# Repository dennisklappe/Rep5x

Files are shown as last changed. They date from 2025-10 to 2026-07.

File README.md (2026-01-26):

# Rep5x - Open source 5-axis 3D printer





5-axis printing demonstration

*Rep5x enables complex geometries without support structures through 5-axis printing*

## Overview

Rep5x democratises 5-axis 3D printing by creating an **affordable retrofit system** for consumer desktop 3D printers. The system adds two rotational axes (A and B) to standard XYZ printers, enabling:

- **Support-free printing** of complex overhangs
- **Improved surface quality** through optimal layer orientation  
- **Stronger parts** by aligning layer direction with stress patterns
- **Reduced material waste** by eliminating support structures

## Quick start

**For easier navigation, visit [Rep5x.com](https://rep5x.com) for the same guides in a more user-friendly format.**

### 1. Check hardware support
Currently supported printers:
- **Ender 5 Pro** - Working prototype
- **Ender 3 V3 SE** - Working prototype with full documentation

### 2. Get the files
- **3D printed parts**: `build-guide/printer-specific/[your-printer]/3d-printed-parts/`
- **Parts list**: `build-guide/universal-parts/bill-of-materials/bom-shared.md`
- **Assembly guide**: `build-guide/assembly-instructions-universal.md`
- **Firmware**: Use the [Firmware Builder](https://tools.rep5x.com/firmware-builder/) to generate custom firmware for your setup

### 3. Join the community
**Discord**: https://discord.gg/GNdah82VBg for build support and discussions

⭐ **Star this repo** to support open-source 5-axis printing development!

## Hardware support

| Printer model | Status | Documentation |
|---|---|---|
| Ender 5 Pro | ✅ Working prototype | Minimal |
| Ender 3 V3 SE | ✅ Working prototype | Complete |
| Generic | Guidelines only | Complete |

## Features

### Current capabilities
- **Continuous C-axis rotation** (unlimited yaw movement)
- **>90° B-axis tilt** for complex geometries
- **Slip ring integration** prevents cable tangling
- **Modular design** for different printer platforms

## Project structure

```
Rep5x/
├── build-guide/             # Complete build documentation
│   ├── assembly-guide.md    # Step-by-step assembly instructions
│   ├── universal-parts/     # Components shared across all printers
│   │   ├── 3d-printed-parts/ # Universal STL files and CAD assembly
│   │   ├── bill-of-materials/ # Complete shared parts list
│   │   ├── electronics/     # Wiring diagrams and control boards
│   │   └── firmware/        # General firmware installation guide
│   └── printer-specific/    # Printer-specific adaptations
│       ├── ender-5-pro/     # Ender 5 Pro retrofit (working)
│       └── ender-3-v3-se/   # Ender 3 V3 SE retrofit (working)
├── website/                 # Official Rep5x website (rep5x.com)
└── README.md               # This file
```

## Community & contributing

### Get help & share builds
**Discord**: https://discord.gg/GNdah82VBg
- Build support and troubleshooting
- Share your prints and modifications
- Development discussions

### Contributing
- Report issues and bugs
- Share your printer modifications  
- Submit pull requests for improvements
- Help with documentation
- Request support for new printer models

**Code of Conduct**: Be respectful and constructive in all interactions.

## Roadmap

### Phase 1 (completed)
- [x] Ender 5 Pro working prototype
- [x] Ender 3 V3 SE adaptation
- [x] Complete documentation and assembly guide
- [x] Marlin firmware configuration
- [x] Setting up the Discord community
- [x] Community guidelines for new printer adaptations

### Phase 2 (current)
- [ ] Community testing and documentation feedback
- [ ] Support users building their first Rep5x systems
- [ ] Identify and fill documentation gaps
- [ ] Accelerate development through user contributions
- [ ] Additional printer model support based on community demand

### Community-driven development
The project's future depends on community involvement. We're focusing on enabling makers to:
- **Adapt to new printer models** with community support
- **Improve documentation** through collaborative contributions
- **Develop slicing features** as open-source solutions
- **Share builds and modifications** to help others

Join our [Discord](https://discord.gg/GNdah82VBg) to help shape the project's direction and contribute to new printer model support!

## License

This project is licensed under the GPL v3 License - see the LICENSE file for details.

## Acknowledgments

This project builds upon the work of [Janis Andersons](https://purl.utwente.nl/essays/96771) at the University of Twente's research into multi-axis 3D printing systems.

---

**Questions?** Follow the repository or join our [Discord](https://discord.gg/GNdah82VBg) for updates as new documentation and features are added.

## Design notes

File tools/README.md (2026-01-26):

# Rep5x - Tools

Web-based tools for Rep5x 5-axis 3D printing.

**Live tools:** https://tools.rep5x.com/

## Available tools

### [Firmware Builder](https://tools.rep5x.com/firmware-builder/)
Configure and build custom Rep5x Marlin firmware with cloud compilation. No local toolchain required.

### [Printer Control](https://tools.rep5x.com/printer-control/)
Control your printer directly from the browser. Jog all 5 axes, send G-code commands, and monitor position.

### [Printer Setup](https://tools.rep5x.com/printer-setup/)
Calibrate Z height and C/B axis zero positions before kinematic calibration.

### [LC/LB Measure](https://tools.rep5x.com/lc-lb-measure/)
Measure your printer's LC and LB kinematic parameters with step-by-step guidance.

### [Vase Generator](https://tools.rep5x.com/vase-generator/)
Generate sample 5-axis vase mode G-code to test and demonstrate Rep5x capabilities.

### [G-code Viewer](https://tools.rep5x.com/gcode-viewer/)
Visualise and animate 5-axis G-code files with collision detection.

### [Calibrator](https://tools.rep5x.com/calibrator/)
Find error curves for your 5-axis system across all C and B angles.

### [G-code Corrector](https://tools.rep5x.com/gcode-corrector/)
Apply calibration corrections and inverse kinematics to 5-axis G-code files.

## File structure

```
tools/
├── index.html           # Tools landing page
├── README.md
├── shared/              # Shared components
│   ├── styles.css
│   ├── theme.js
│   ├── storage-manager.js
│   ├── printer-interface.js
│   ├── camera-manager.js
│   ├── header.js
│   ├── footer.js
│   ├── inverse-kinematics.js
│   ├── c-axis-optimizer.js
│   ├── calibration-corrector.js
│   ├── calibration-visualizer.js
│   ├── calibration-visualizer-3d.js
│   └── correction-graph-renderer.js
├── firmware-builder/
├── printer-control/
├── printer-setup/
├── lc-lb-measure/
├── vase-generator/
├── gcode-viewer/
├── calibrator/
└── gcode-corrector/
```

## Support

- **Discord**: [Join our community](https://discord.gg/GNdah82VBg)

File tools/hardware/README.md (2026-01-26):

# Rep5x Tools - Hardware

Shared hardware components for Rep5x web tools.

## Available hardware

### [`rep5x-camera/`](rep5x-camera/)

USB camera module for visual calibration and alignment tasks.

**Used by:**
- [LC/LB Measure](../lc-lb-measure/) - Camera-based LC/LB parameter measurement

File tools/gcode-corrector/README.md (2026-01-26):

# Rep5x - G-code corrector

Apply calibration corrections and inverse kinematics to 5-axis G-code files.

**Live tool:** https://tools.rep5x.com/gcode-corrector/

## Features

- **Calibration correction**: Apply error compensation from calibration data to improve print accuracy
- **Inverse kinematics**: Add software IK to convert tool-tip coordinates to machine coordinates
- **Firmware IK support**: Apply calibration corrections to G-code already processed with firmware IK (firmware IK in the working, will update woon)
- **Visual preview**: 3D visualisation showing uncalibrated vs calibrated nozzle paths
- **Demo generation**: Create calibration test files to verify corrections

## Use cases

### 1. Apply calibration to uncalibrated files
For G-code generated without calibration:
1. Load your calibration data (from [calibrator tool](https://tools.rep5x.com/calibrator/))
2. Upload uncalibrated G-code
3. Enable "Apply calibration corrections"
4. Process and download corrected file

### 2. Add software IK to raw files
For G-code with tool-tip coordinates only:
1. Enter your LC and LB parameters
2. Upload G-code file
3. Enable "Apply inverse kinematics"
4. Process and download with IK applied

### 3. Calibrate firmware IK files (hopefully soon firmware IK will be available!)
For G-code already processed with firmware IK:
1. Load your calibration data
2. Upload firmware IK G-code
3. Enable "Apply calibration corrections"
4. The corrector automatically detects firmware IK and applies calibration in the correct mode
5. Download corrected file

## Quick start

1. Go to https://tools.rep5x.com/gcode-corrector/
2. **Load calibration** (optional): Click "Load calibration data" and select your `.json` file from the [calibrator tool](https://tools.rep5x.com/calibrator/)
3. **Upload G-code**: Drag and drop or click to select your G-code file
4. **Configure options**:
   - Check "Apply inverse kinematics" if your file needs IK (enter LC/LB values)
   - Check "Apply calibration corrections" if you loaded calibration data
5. **Process**: Click "Process G-code"
6. **Download**: Click "Download corrected G-code"

## Processing modes

The corrector supports three processing modes:

### Software IK + Calibration
- Input: Tool-tip coordinates (XYZ at various A/B angles)
- Output: Machine coordinates with IK applied, then calibration corrections applied
- Use for: Raw G-code that needs both IK and calibration

### Calibration only (firmware IK mode)
- Input: G-code already processed with firmware IK
- Output: Calibration corrections applied to existing machine coordinates
- Use for: Files from slicers that apply firmware IK

### IK only
- Input: Tool-tip coordinates
- Output: Machine coordinates with IK applied
- Use for: Testing IK without calibration, or when no calibration data available

## Understanding the visualisation

The 3D preview shows nozzle error patterns with two colored spheres:
- **Red sphere/trail**: C sweep errors (C rotating 0-360° at B=0)
- **Orange sphere/trail**: B sweep errors (B tilting -90 to +90° at C=0)

**Mode toggle** (above the visualizer):
- **Uncalibrated**: Shows full error pattern without calibration applied
- **Calibrated**: Shows residual error after calibration corrections are applied

**What good calibration looks like**: In calibrated mode, both spheres should barely move from the white center marker. If the movement looks similar in both modes, your calibration isn't working well.

**Preview controls** (below the visualizer): The sweep mode buttons (Both, C only, B only, Combined) only change what you see in the animation. Downloaded demo G-code always tests both C and B axes.

## Demo G-code generation

Generate test files to verify your calibration on the actual printer:

1. **Load calibration data**
2. **Set centre position**: Enter XYZ coordinates where the nozzle should stay fixed
3. **Generate**: Click "Uncalibrated" or "Calibrated" to download demo G-code

**What the demo does**: The printer performs a combined A+B sweep (A rotates 360° while B oscillates sinusoidally), testing both axes simultaneously. The nozzle tip should remain at the specified centre position throughout the entire movement.

**Expected results**:
- **Uncalibrated demo**: Nozzle will drift away from centre, showing your printer's error pattern
- **Calibrated demo**: Nozzle should stay at centre (if calibration is working correctly)

Use these demos to:
- Verify calibration accuracy visually on the printer
- Test before applying corrections to real prints
- Compare uncalibrated vs calibrated performance side-by-side

## File structure

```
gcode-corrector/
├── index.html              # Main application
├── README.md               # This file
└── js/
    ├── app.js              # Application controller
    ├── gcode-processor.js  # G-code parsing and correction engine
    └── calibration-corrector.js  # (in /shared) Calibration data handler
```

## G-code header detection

The corrector automatically detects Rep5x G-code headers to determine:
- Whether IK is already applied (software or firmware)
- LC and LB parameters used
- Whether calibration corrections are present
- Which tool generated the file

This helps prevent double-applying corrections.

## Tips

- Always test corrected G-code with demo files first
- Keep your original uncalibrated files as backups
- Recalibrate periodically as your printer's mechanical state changes
- The corrector preserves all comments and metadata from the original file

## Support

- **Discord**: [Join our community](https://discord.gg/GNdah82VBg)

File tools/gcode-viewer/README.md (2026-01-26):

# Rep5x - G-code viewer

Visualise and animate 5-axis G-code files with real-time printhead orientation display.

**Live tool:** https://tools.rep5x.com/gcode-viewer/

## Features

- **5-axis visualisation**: Full support for C-axis (yaw) and B-axis (pitch) movements
- **Inverse kinematics**: Automatically detects and reverses IK corrections to show original path
- **Animation controls**: Play, pause, speed control, and progress scrubbing
- **Collision detection**: Warns when printhead would collide with printed path or bed
- **Interactive 3D view**: Mouse controls for rotating and zooming

## Usage

1. **Load G-code**: Upload a Rep5x G-code file
2. **Review info**: Check file information and IK parameters
3. **Control animation**: Use play/pause and speed slider
4. **Adjust view**: Toggle visibility of path, printhead, and axes

## File structure

```
gcode-viewer/
├── index.html
├── README.md
└── js/
    ├── app.js
    ├── gcode-parser.js
    ├── inverse-kinematics-reverser.js
    ├── animation-engine.js
    ├── collision-detector.js
    ├── scene-objects.js
    ├── camera-controls.js
    ├── ui-controller.js
    ├── file-handler.js
    └── printheads/
        ├── printhead-base.js
        └── ender3-v3-se.js
```

## Support

- **Discord**: [Join our community](https://discord.gg/GNdah82VBg)

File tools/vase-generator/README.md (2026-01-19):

# Rep5x - Vase generator

Generate demonstration G-code files to showcase Rep5x 5-axis printing capabilities with various shapes.

**Live tool:** https://tools.rep5x.com/vase-generator/

## Features

- **Multiple shapes**: Elbow pipe, mushroom
- **Interactive 3D preview**: Real-time visualisation of generated models
- **Configurable parameters**: Diameter, height, layer settings, speeds
- **5-axis toolpaths**: Each shape demonstrates different 5-axis printing techniques
- **Ready-to-print output**: Complete G-code files with inverse kinematics

## Usage

1. **Select shape**: Choose from available shapes in the sidebar
2. **Adjust parameters**: Modify size, layer height, and print speeds
3. **Preview model**: View real-time 3D preview
4. **Generate G-code**: Click generate to create printer-ready G-code
5. **Download file**: Save for printing on your Rep5x printer

## File structure

```
vase-generator/
├── index.html
├── README.md
└── js/
    ├── app.js
    └── shapes/
        ├── elbow-pipe.js
        └── mushroom.js
```

## Support

- **Discord**: [Join our community](https://discord.gg/GNdah82VBg)

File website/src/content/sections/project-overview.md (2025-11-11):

---
title: "Rep5x Project Overview"
description: "An open-source research project developing affordable 5-axis printing retrofits for consumer 3D printers, enabling new printing capabilities through community collaboration."
badge: "Project Features"

list_columns:
  - title: "5-Axis Motion Control <br> Implementation"
    images:
      - "/images/rw2-print-head-cad.webp"
    description: "Adding yaw and pitch rotation to standard 3D printers lets you print complex shapes without support material, reducing reliance on support structures."
    list:
      - icon: "lucide:rotate-3d"
        title: "Coordinated Multi-Axis Movement"
        description: "Continuous yaw rotation and >90° pitch tilt allow parts to be printed from optimal angles."
      - icon: "lucide:minimize"
        title: "Support Structure Reduction"
        description: "Strategic part orientation can eliminate support material for many complex geometries."

  - title: "Open-Source Retrofit System Design"
    images:
      - "/images/blog/github-repo-screenshot.webp"
    description: "Complete documentation and modular design allow adaptation to different printer models, with community contributions driving development forward."
    list_check:
      - "CAD files and build documentation available on GitHub"
      - "Marlin firmware modifications for 5-axis control"
      - "Currently tested on Ender 5 Pro platform"
      - "Community-driven adaptation to additional printer models"
    button:
      enable: true
      label: "View Project"
      link: "https://github.com/dennisklappe/rep5x"
---

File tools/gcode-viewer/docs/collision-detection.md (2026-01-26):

# Collision detection

This document explains how the collision detection system works in the G-code viewer.

## Overview

```mermaid
flowchart TD
    A[User enables collision detection] --> B[Get printhead parameters]
    B --> C[Loop through all G-code commands]
    C --> D{Command has movement?}
    D -->|No| C
    D -->|Yes| E[Update position]
    E --> F{Path > 20 points AND\n> 10 steps since last collision?}
    F -->|No| G{Has extrusion?}
    F -->|Yes| H[Check collisions]
    H --> J{Collision detected?}
    J -->|Yes| K[Record collision point]
    J -->|No| G
    K --> G
    G -->|Yes| I[Add point to printed path]
    G -->|No| C
    I --> C
    C -->|Done| L[Display collision markers]
```

### Why these checks?

- **Path > 20 points**: Skip collision checks at the start when there's barely anything printed yet
- **> 10 steps since last collision**: Avoid recording hundreds of collision points in the same area
- **Has extrusion**: Only extruded material is added to the path (you can't collide with air)
- **All moves are checked**: Both travel moves (G0) and print moves (G1) check for collisions with the printed path

## Collision check process

For each position, the system checks if any part of the printhead collides with the build plate or previously printed path.

```mermaid
flowchart TD
    subgraph Input
        A[Current position X, Y, Z, A, B]
        B[Printed path points]
        C[Printhead geometry]
    end

    A --> D[Build rotation matrix from C and B angles]

    D --> E{Check build plate collisions}
    E --> F[Heatblock corners]
    E --> G[Nozzle bottom edge]
    E --> H[Cable outer end]

    F --> I{Any point Y < 0?}
    G --> I
    H --> I

    I -->|Yes| J[Return: Collision!]
    I -->|No| K{Check path collisions}

    K --> L[For each path point]
    L --> M[Transform to local printhead space]
    M --> N{Inside nozzle cylinder?}
    M --> O{Inside heatblock box?}
    M --> P{Inside cable cylinder?}

    N -->|Yes| J
    O -->|Yes| J
    P -->|Yes| J

    N -->|No| O
    O -->|No| P
    P -->|No| Q{More path points?}
    Q -->|Yes| L
    Q -->|No| R[Return: No collision]
```

## Printhead geometry

The printhead is defined in local space with the nozzle tip at the origin.

```mermaid
flowchart LR
    subgraph Printhead components
        A[Nozzle cylinder]
        B[Heatblock box]
        C[Cable cylinder]
    end

    subgraph Nozzle
        A1[radius: 4.5mm]
        A2[bottom: 2mm]
        A3[top: 8mm]
    end

    subgraph Heatblock
        B1[halfSize: 12 x 10 x 12mm]
        B2[center: 2, 18, 0mm]
    end

    subgraph Cable
        C1[radius: 3mm]
        C2[center: -15, 18, 0mm]
        C3[halfLength: 5mm]
    end

    A --> A1
    A --> A2
    A --> A3
    B --> B1
    B --> B2
    C --> C1
    C --> C2
    C --> C3
```

## Coordinate transformation

The collision detection uses matrix transformations to check collisions efficiently.

```mermaid
flowchart TD
    subgraph "Build plate collision"
        A1[Local printhead point] --> B1[Apply rotation matrix]
        B1 --> C1[Add nozzle tip position]
        C1 --> D1{World Y < 0?}
        D1 -->|Yes| E1[Collision with bed]
    end

    subgraph "Path collision"
        A2[World path point] --> B2[Subtract nozzle tip position]
        B2 --> C2[Apply inverse rotation matrix]
        C2 --> D2[Local space point]
        D2 --> E2{Inside component bounds?}
        E2 -->|Yes| F2[Collision with path]
    end
```

## Component collision checks

### Nozzle cylinder
```
distance_from_axis = sqrt(x² + z²)
collision = distance_from_axis < radius AND y > bottom AND y < top
```

### Heatblock box
```
relative = point - center
collision = |rel.x| < halfSize.x AND |rel.y| < halfSize.y AND |rel.z| < halfSize.z
```

### Cable cylinder (horizontal along X)
```
relative = point - center
distance_from_axis = sqrt(rel.y² + rel.z²)
collision = distance_from_axis < radius AND |rel.x| < halfLength
```

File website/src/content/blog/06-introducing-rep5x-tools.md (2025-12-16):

---
title: 'Introducing Rep5x Tools'
description: 'Browser-based tools to help you set up, calibrate, and control your Rep5x 5-axis printer.'
date: 2025-12-15
image: '/images/blog/tools-overview.webp'
categories: ['tools', 'software']
author:
  name: 'Dennis Klappe'
  designation: 'Masters Student'
  avatar: '/images/team/dennis-klappe.webp'
featured: true
---

**Rep5x Tools** is a collection of browser-based tools to help you set up, calibrate, and use your 5-axis printer. No installation needed, just open your browser and connect to your printer.

<div class="rounded" style="overflow: hidden;">
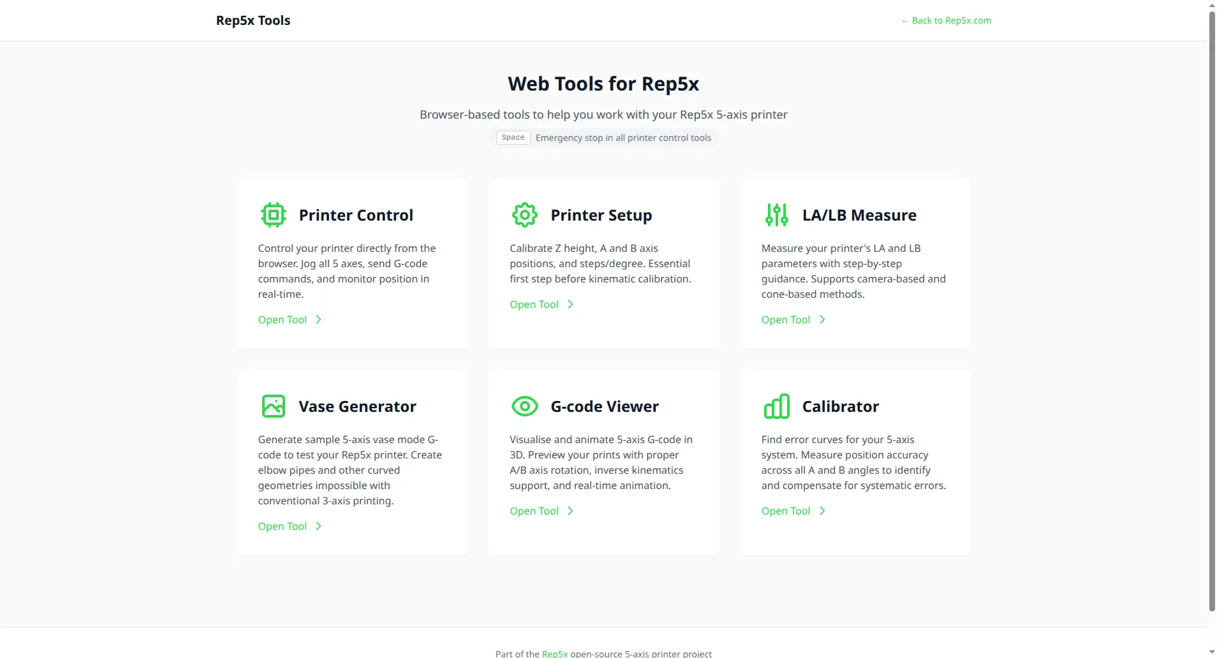
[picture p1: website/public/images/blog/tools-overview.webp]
Rep5x Tools overview

</div>

## Available tools

### Printer Control

Control your printer directly from the browser. Jog all 5 axes, send G-code commands, and monitor position in real-time. Press Space for emergency stop.

<div class="rounded" style="overflow: hidden;">
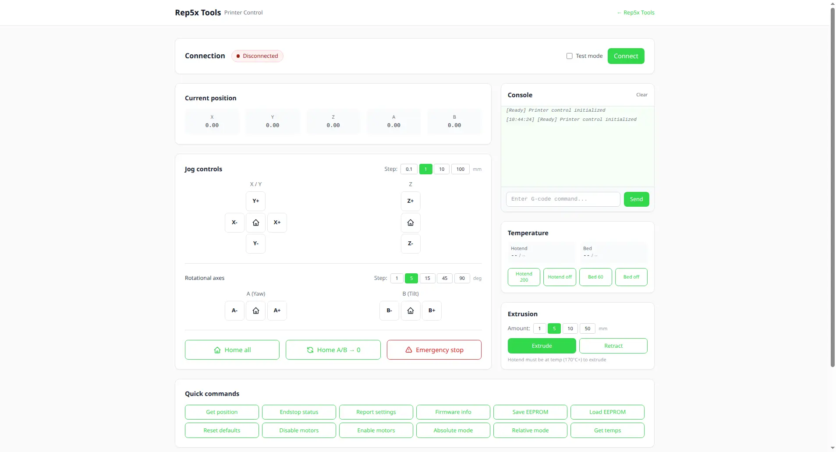
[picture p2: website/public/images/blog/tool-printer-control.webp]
Printer Control tool

</div>

### Printer Setup

Calibrate Z height, A and B axis positions, and steps/degree. This is the essential first step before kinematic calibration.

<div class="rounded" style="overflow: hidden;">
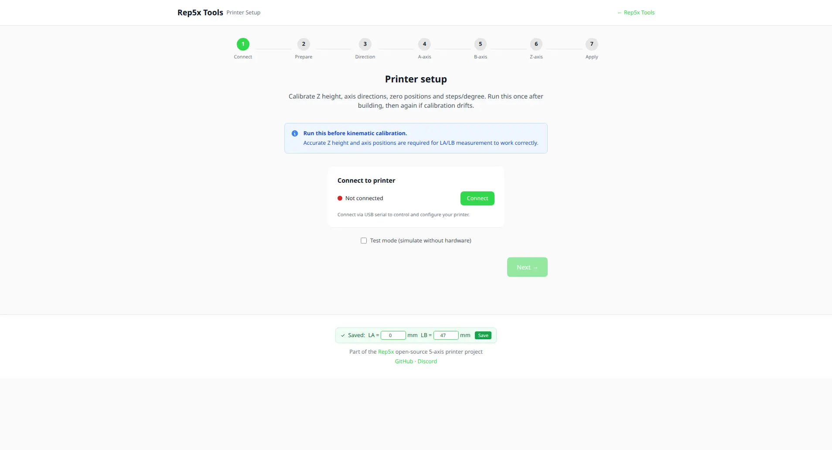
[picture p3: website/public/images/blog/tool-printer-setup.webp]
Printer Setup tool

</div>

### LA/LB Measure

Measure your printer's LA and LB kinematic parameters with step-by-step guidance. Supports both camera-based and cone-based measurement methods.

<div class="rounded" style="overflow: hidden;">
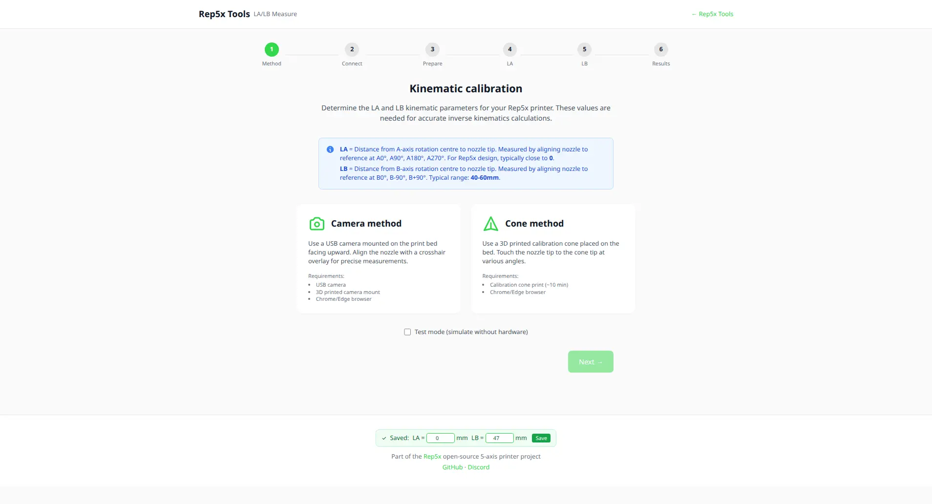
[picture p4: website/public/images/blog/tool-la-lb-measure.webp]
LA/LB Measure tool

</div>

### Vase Generator

Generate sample 5-axis vase mode G-code to test your printer. Create elbow pipes, mushroom vases, and other curved geometries that are impossible with conventional 3-axis printing.

<div class="rounded" style="overflow: hidden;">
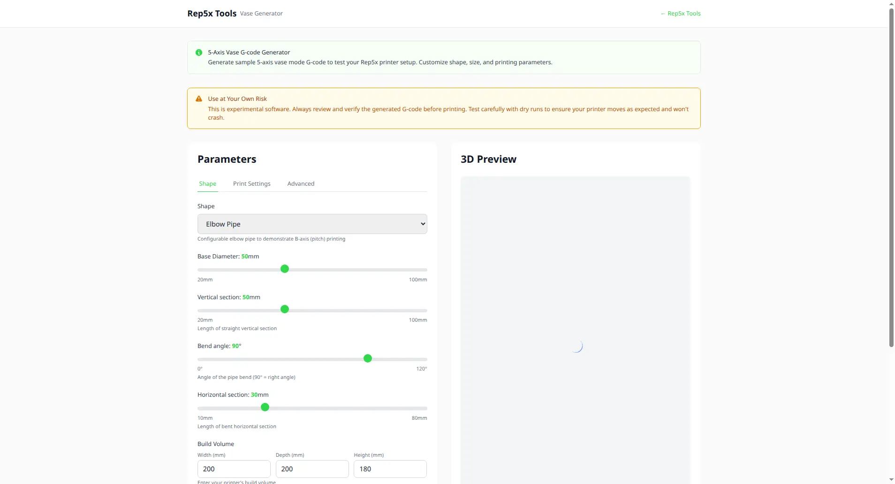
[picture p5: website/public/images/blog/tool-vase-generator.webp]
Vase Generator tool

</div>

### G-code Viewer

Visualise and animate 5-axis G-code in 3D. Preview your prints with proper A/B axis rotation, inverse kinematics support, collision detection, and real-time animation.

<div class="rounded" style="overflow: hidden;">
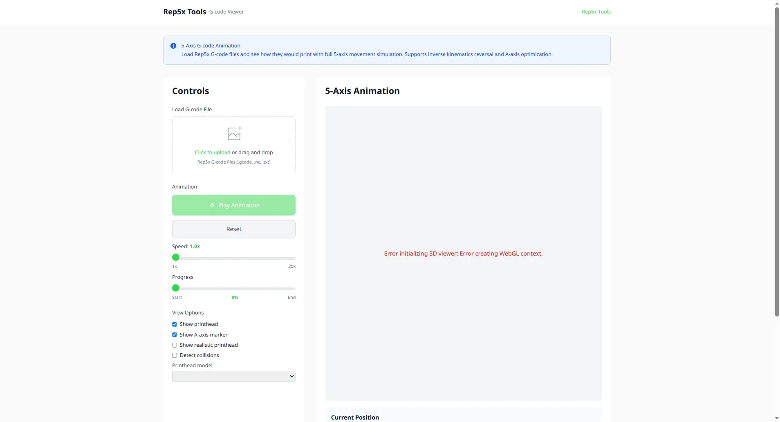
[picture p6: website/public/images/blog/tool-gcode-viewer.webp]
G-code Viewer tool

</div>

## Hardware: Rep5x Camera

Some tools work even better with the optional **Rep5x Camera** module, a simple USB camera with built-in LED lighting that mounts to your printer's bed.

<div class="rounded" style="overflow: hidden;">
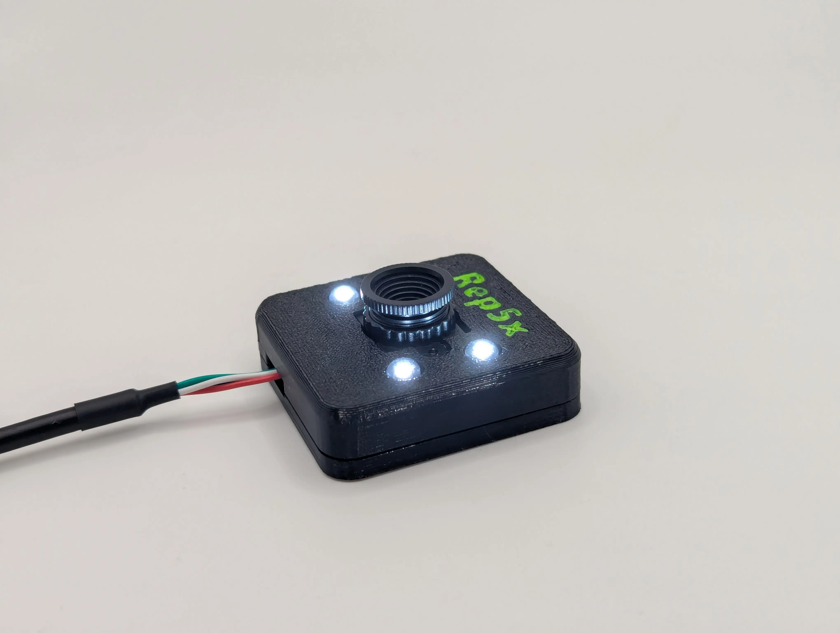
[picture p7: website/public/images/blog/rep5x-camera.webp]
Rep5x Camera module

</div>

The camera enables precise measurements by providing a close-up view of the nozzle. In the LA/LB Measure tool, you align the nozzle tip to a crosshair on screen and confirm the position. Much easier than eyeballing it from the side of your printer.

The upcoming Calibrator tool will also use this camera for automated error mapping across all A and B angles. If you don't want to build the camera module, no problem. **All tools have alternative methods** that work without additional hardware, like the cone-based measurement method already available in LA/LB Measure.

## Coming soon: Calibrator

The **Calibrator** tool is currently in development. It works like bed leveling mesh but for your rotational axes. Measure position errors across different A and B angles to generate error curves, then run your G-code through the tool to apply compensation.

## Try it out

All tools are available at [tools.rep5x.com](https://tools.rep5x.com). Connect to your printer via USB and you're good to go.

Questions or feedback? **[Join our Discord](https://discord.gg/GNdah82VBg)**!

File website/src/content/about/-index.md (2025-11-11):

---
title: "About Rep5x"
meta_title: "About Rep5x"
description: "Open-source 5-axis 3D printing retrofit system developed at University of Twente"
image: "/images/about/ender-5-pro-rw2-printing.webp"

hero:
  title: "Democratising 5-Axis 3D Printing Technology"
  description: "Rep5x is an open-source research project developing affordable retrofit systems that transform consumer 3D printers into 5-axis manufacturing platforms"
  image: "/images/about/ender-5-pro-rw2-printing.webp"

card:
  title: "Research-driven innovation"
  subtitle: "Academic Excellence"
  description: "Rep5x originated from academic research at the University of Twente, building on previous work in multi-axis 3D printing. Our goal is to make advanced manufacturing capabilities accessible to makers, educators, and small businesses through open-source design and comprehensive documentation. The project emphasises community collaboration and knowledge sharing to advance the field of additive manufacturing."
  icon: "lucide:map-pin"

accomplishments:
  enable: true
  list:
    - number: "6"
      prefix: ""
      subtitle: "Total axes (X, Y, Z, E + yaw & pitch)"
    - number: "360"
      prefix: "°"
      subtitle: "Continuous yaw rotation"
    - number: "100"
      prefix: "%"
      subtitle: "Open-source design"
---

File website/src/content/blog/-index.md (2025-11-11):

---
title: "Blog Posts"
meta_title: ""
description: "Rep5x project updates and 5-axis printing insights"
image: "/images/blog/ender-5-pro-rw2-retrofit.webp"

hero:
  title: "Rep5x Development Blog"
  description: "Follow the development journey of open-source 5-axis printing technology, research insights, and community updates"
---

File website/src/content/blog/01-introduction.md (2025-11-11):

---
title: 'The journey begins'
description: 'Introduction to the Rep5x 5-axis printing project and thesis journey at University of Twente'
date: 2025-09-01
image: '/images/blog/ender-5-pro-rw2-retrofit.webp'
categories: ['project', 'introduction']
author:
  name: 'Dennis Klappe'
  designation: 'Masters Student'
  avatar: '/images/team/dennis-klappe.webp'
featured: true
---

Welcome to my thesis blog! I'm Dennis Klappe, a Master's student in Industrial Design Engineering at the University of Twente. I'm not the kind of person who uses social media much or enjoys blogging, but I believe documenting the process well is key to creating a good open-source project. So bear with me as I share this journey over the next nine months, working on making 5-axis FDM 3D printing more accessible.

## The challenge

Most traditional FDM 3D printers work in three axes (X, Y, and Z). Adding two rotational axes enables printing complex geometries without supports, better surface quality, and less waste. But current 5-axis printers are expensive and complex.

My goal: develop an affordable, open-source 5-axis system that works with common desktop 3D printers.

## Building on previous work

This project builds on my supervisor Janis Andersons's [master's thesis](https://purl.utwente.nl/essays/96771) from 2023. He developed a 5-axis printer using a 2-axis print-head retrofit (adding 2 rotational axes to the standard 3-axis system), proving that multi-axis printing can be accessible. My work continues this development, focusing on refinement and democratisation.

## What's coming

Over the coming months, I'll probably work on:
- Understanding user needs
- Creating build documentation
- Testing real-world performance
- Building a community around the project
- Updating the hardware the adapt to mutliple existing printers

## Get involved

This blog will document the development process, successes, failures, and everything in between. Whether you're a maker, educator, or just curious about 3D printing's future, follow along.

Want to discuss the project or contribute? [Join the Discord](https://discord.gg/75Hy5dMwTJ) to connect with the community.

The best ideas often come from makers and citizen-scientists. Let's democratise 5-axis printing together.

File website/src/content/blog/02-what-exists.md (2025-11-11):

---
title: 'Current state printer'
description: 'Understanding the existing Rep5x hardware and building on previous research achievements'
date: 2025-09-15
image: '/images/blog/cad-model-rw2-print-head.webp'
categories: ['hardware', 'history']
author:
  name: 'Dennis Klappe'
  designation: 'Masters Student'
  avatar: '/images/team/dennis-klappe.webp'
---

In 2023, my supervisor Janis Andersons built the first version of this 5-axis printer for his master's thesis. He took a standard Ender 5 Pro and added a 2-axis print-head retrofit that could tilt and rotate the nozzle.

## What Janis achieved

Janis designed what he called the "robot wrist" (RW2), a print-head that adds two rotational axes to a standard printer. The A-axis rotates around the vertical Z-axis (like turning your head left and right), while the B-axis tilts the nozzle forward and back.

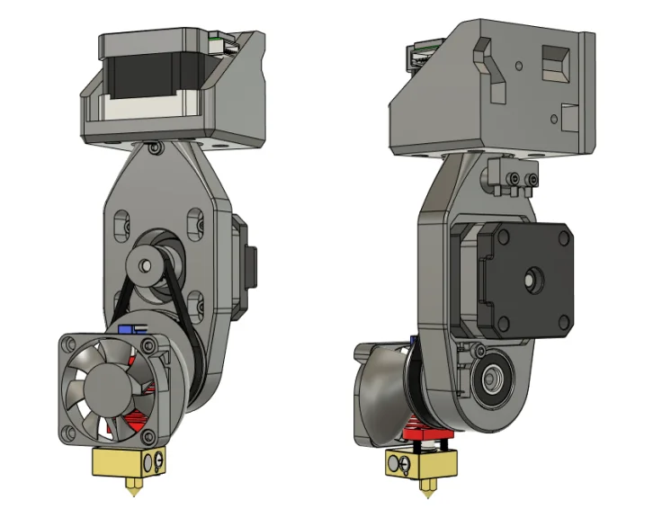
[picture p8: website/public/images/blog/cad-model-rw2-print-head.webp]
CAD model of RW2 print-head

*CAD model of RW2 print-head (Andersons, 2023)*

He kept it simple. The design uses standard NEMA17 stepper motors with 3 to 1 belt reduction for both axes. Everything can be 3D printed except for some bearings, belts, and electronics. The whole retrofit costs under €150.

His test prints proved the concept. He printed tubes with 90-degree overhangs without any supports. Surface quality on angled surfaces improved compared to standard printing. The dimensional accuracy stayed within 0.6mm, which is decent for a first prototype.

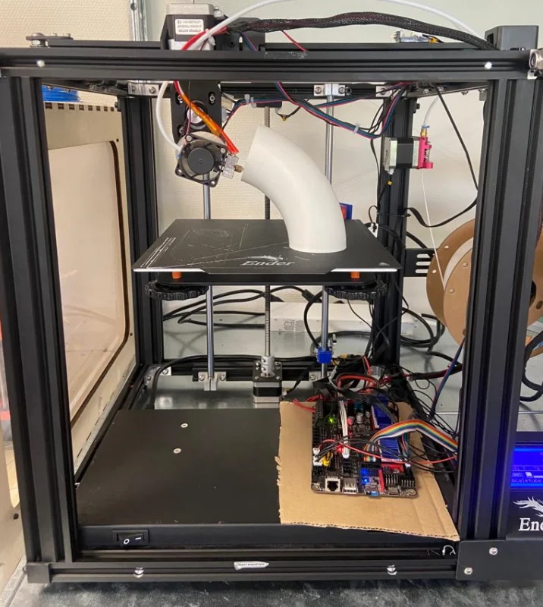
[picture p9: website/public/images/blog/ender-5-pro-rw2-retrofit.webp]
Ender 5 Pro with retrofit RW2 print-head, executing a large print

*Ender 5 Pro with retrofit RW2 print-head, executing a large print (Andersons, 2023)*

## Hardware details

Why did Janis choose specific components? Most 3D printer boards support 5 stepper motors (X, Y, Z1, Z2, E), but 5-axis printing needs 6 motors (X, Y, Z, A, B, E). Janis used the BTT Octopus board with TMC2208 stepper drivers, costing €107.50 for the electronics (way cheaper nowadays).
 
The mechanical design keeps things simple. Most parts can be 3D printed, and the rest are standard components you probably have lying around.

### Key components (simplified)
- **Motors**: 2x NEMA17 steppers (€24 total)
- **Bearings**: 608 2RS bearings (€0.64)
- **Belts and pulleys**: GT2 timing belt and pulleys (€12.60)
- **Hardware**: Various M3 bolts and heat-set inserts (€3)
- **3D printed parts**: About 27g of filament
- **Total mechanical parts**: ~€33

With the BTT Octopus board and drivers, the total retrofit cost comes to around €140.

## Current status

So where does that leave us? We have a working 5-axis printer. It prints overhangs without supports, improves surface quality on angled faces, and costs less than €150 to build.

But it's not perfect. The RW2 print-head reduced the build height, the accuracy got worse and the B-axis motor overheats during long prints. Complicated parts do not print well at the moment. Most importantly, there's no easily accessible software to actually use these capabilities or a way for other makers to recreate the project.

That's where my work begins. The hardware exists, it's been tested, and it works. Now we need to make it accessible to everyone else.

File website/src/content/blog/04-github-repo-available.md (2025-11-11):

---
title: 'GitHub repo now available'
description: 'First public release of Rep5x design files and documentation for the community'
date: 2025-10-20
image: '/images/blog/github-repo-screenshot.webp'
categories: ['community', 'open-source']
author:
  name: 'Dennis Klappe'
  designation: 'Masters Student'
  avatar: '/images/team/dennis-klappe.webp'
---

I'm always having a hard time publishing things that are unpolished or not worked out enough yet. But I've had many people messaging me for the past week asking if there are already files available and that they'd just like to have a look at it.

So here's a release of the very pre-alpha files and some basic instructions. This will improve soon.

## What's available now

The [Rep5x GitHub repository](https://github.com/dennisklappe/rep5x) is now live with:

- Ender 5 Pro working prototype
- Complete bill of materials with all parts needed
- Marlin firmware configurations for BTT Octopus V1.1 (tested) and Pro H723 (in development)
- Wiring diagrams for electronics setup
- Basic documentation to get started

## Current status

This is a pre-alpha release. The Ender 5 Pro configuration represents a working prototype that's been tested, but documentation is still being refined.

The firmware uses Marlin 2.1.x with configurations for two control boards. The V1.1 board configuration is proven working. The Pro H723 configuration is in development for the Ender 3 V3 SE conversion.

## Repository structure

I'm not 100% sure yet how to structure the repo. Please let me know what would work well. Current structure organises by printer models and firmware by control board type.

I tried to keep things simple. Hardware files go in printer-specific folders. Firmware configurations are organised by the actual control board used, not by printer model, since the same board can work across different printers.

## Get involved

The project is very much community-driven. Your feedback on repository organisation and documentation would help a lot.

Join the [Discord](https://discord.gg/75Hy5dMwTJ) for discussions, support, and feedback. Or check out the [GitHub repo](https://github.com/dennisklappe/rep5x) and let me know what you think.

More detailed assembly instructions, calibration guides, and additional printer support will be added as development continues.

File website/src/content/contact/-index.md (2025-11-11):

---
title: "Contact"
meta_title: ""
description: "Get in touch with the Rep5x team for support, questions, or to contribute to the open-source 5-axis printing project"
draft: false

contact_section:
  title: "Connect with Rep5x Team"
  description: "Get in touch with the Rep5x team for questions about 5-axis printing technology, collaboration opportunities, or technical support. For direct contact with team members, visit our [about page](/about)."
  form:
    title: "Reach Out to Us"
    description: "Whether you're interested in 5-axis printing technology, have questions about our open-source project, or want to collaborate, we'd love to hear from you."
  list:
    - icon: lucide:mail
      title: Email Us
      description: hello@rep5x.com
    - icon: lucide:message-circle
      title: Discord
      description: "[rep5x.com/discord](https://discord.gg/75Hy5dMwTJ)"
    - icon: lucide:map-pin
      title: Location
      description: University of Twente
---

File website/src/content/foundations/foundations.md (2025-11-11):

---
# Our Customers
title: "Built on open source foundations"
brands:
  - src: "/images/foundation-logos/university-twente.webp"
    alt: "University of Twente"
  - src: "/images/foundation-logos/marlin.webp"
    alt: "Marlin Firmware"
  - src: "/images/foundation-logos/github.webp"
    alt: "GitHub"
  - src: "/images/foundation-logos/astro.webp"
    alt: "Astro"
  - src: "/images/foundation-logos/oshwa.webp"
    alt: "OSHWA"
  - src: "/images/foundation-logos/creative-commons.webp"
    alt: "Creative Commons"
---

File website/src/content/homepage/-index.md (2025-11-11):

---
# Banner
banner:
  title: "Rep5x: Open-Source 5-Axis Printing"
  content: "Research project developing affordable retrofit systems to add 5-axis capabilities to consumer 3D printers, with complete documentation and community collaboration."
  main_image:
    src: "/images/5axis-printer-demo.gif"
    alt: "5-Axis Printer Demo"
  background_image:
    src: "/images/hero_background.svg"
    alt: "hero_blob"
  buttons:
    - enable: true
      label: "Join Discord"
      link: "https://discord.gg/75Hy5dMwTJ"
    - enable: true
      label: "Star on GitHub"
      link: "https://github.com/dennisklappe/rep5x"

#solution
solution_section:
  enable: true
  title: "How Rep5x Works"
  content: "A retrofit system that adds yaw and pitch rotation to existing 3D printers, letting you print complex shapes without support material."
  badge: "Technical Overview"
  cards:
    - title: "Retrofit Design"
      content: "Adds yaw and pitch rotation axes to existing 3D printers with continuous yaw rotation and >90° pitch tilt range."
      icon: "lucide:settings"
    - title: "Reduced Support Requirements"
      content: "Yaw and pitch rotation allow printing complex geometries support-free, eliminating support structures for many overhangs."
      icon: "lucide:layers-3"
    - title: "Better Part Strength"
      content: "Control over layer orientation allows for stronger parts by aligning print layers with load directions and stress patterns."
      icon: "lucide:layers"
    - title: "Material Efficiency"
      content: "Reduced support material usage decreases waste and post-processing time for suitable part geometries."
      icon: "lucide:recycle"
    - title: "Modular Implementation"
      content: "Currently implemented for Ender 5 Pro and Ender 3 V3 with modular design allowing adaptation to other consumer printer platforms."
      icon: "lucide:puzzle"
    - title: "Open-Source Development"
      content: "Complete documentation on GitHub enables community contributions and adaptations to additional printer models."
      icon: "lucide:github"

---

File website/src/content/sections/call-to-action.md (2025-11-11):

---
enable: true
title: "Start Building Your 5-Axis Printer"
image: "/images/cta_background.svg"
description: "Join the community developing affordable 5-axis printing solutions. <br> Access complete documentation, firmware, and collaborate with other builders."
button:
  enable: true
  label: "Join Discord"
  link: "https://discord.gg/75Hy5dMwTJ"
---

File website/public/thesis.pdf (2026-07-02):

M S C T H E S I S | U N I V E R S I T Y O F T W E N T E

# DEMOCRATISING MULTI-AXIS 3D PRINTING

## Making an open-source system to bring multi-axis 3D printing to everyday makers

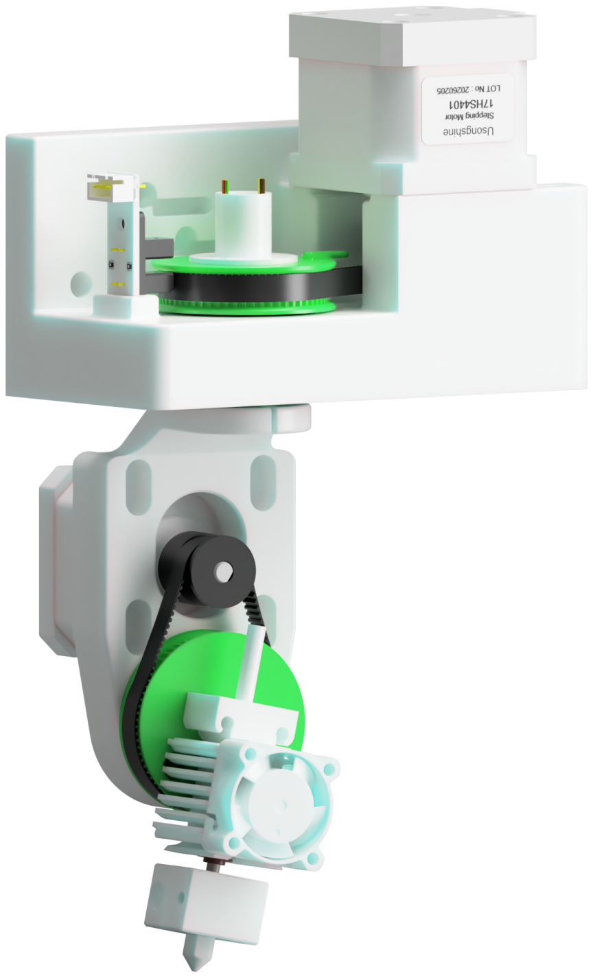
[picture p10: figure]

A U T H O R
Dennis Klappe
s2400758

G R A D U A T I O N C O M M I T T E E Dr.ir. T. Vaneker (chair)
Ir. J. Andersons (supervisor)
Dr. M. Pereira (external member)

P R O G R A M M E
MSc Industrial Design
Engineering
DPM, Faculty of ET

P L A C E & D A T E
Enschede, 2 July 2026

# CONTENTS

01 | Introduction | 8
1.1 | Background | 9
1.2 | Fused deposition modelling | 10
1.3 | Multi-axis printing | 10
1.4 | Prior work | 12
1.5 | Problem statement | 13
1.6 | Research objectives | 13
1.7 | Research questions | 14
1.8 | Scope and boundaries | 14
1.9 | Thesis outline | 14
02 | Literature review | 15
2.1 | Multi-axis additive manufacturing | 16

### 2.2 Open-source hardware and the maker ecosys-

| tem | 18

### 2.3 Technology adoption, accessibility, and com-

| munity | 20
2.4 | Discussion | 25
03 | Methodology | 27
3.1 | Research paradigm | 28
3.2 | Research process | 28
3.3 | Evaluation methods | 30
3.4 | Limitations | 31
3.5 | Ethical considerations | 31
04 | Analysis and requirements | 32
4.1 | Concrete gaps in the existing system | 33
4.2 | Analysis of existing solutions | 33
4.3 | Stakeholders | 34
4.4 | Target user pro*le | 35
4.5 | Requirements speci*cation | 35
4.6 | Requirements traceability | 36
05 | Design and development | 38
5.1 | Hardware design | 39
5.2 | Firmware | 45
5.3 | So,ware tools | 46
5.4 | Open-source release and community | 54
5.5 | Adoption impact | 54
5.6 | Design trade-o-s | 55
06 | Evaluation | 56
6.1 | Pre-build interest survey | 57
6.2 | Discord and the iteration loop | 57
6.3 | The adoption funnel | 58
6.4 | Independent build attempts | 59
6.5 | What the evaluation supports | 59
07 | Discussion | 61
7.1 | Key *ndings | 62
7.2 | Answering the research questions | 62
7.3 | Implications | 62
7.4 | Limitations | 62
7.5 | Re1ection on direction | 63
7.6 | Future work | 63
08 | Conclusion | 64
8.1 | Summary | 65
8.2 | Contributions | 65
8.3 | Recommendations | 65
8.4 | Closing remarks | 65
References | 66
Appendices | 70

# ABSTRACT

Multi-axis 3D printing promises support-free overhangs, smoother curved surfaces, and parts whose layers follow their load paths. Yet it stays con*ned to research labs and industry. The technology isn’t the obstacle: earlier work already showed that an a-ordable *ve-axis retro*t of a consumer FDM printer works. The obstacle is accessibility. A working prototype existed, but reproducing it meant commercial so,ware, specialist knowledge, and far more e-ort than the makers it was meant for could reasonably take on.
This thesis asks why a working prototype isn’t being reproduced, and what it takes to change that. Following a Design Science Research approach, the adoption barriers are diagnosed through Rogers’ di-usion of innovations and the open-source-hardware reproducibility literature, then addressed directly. The result is Rep5x: a *ve-axis retro*t redesigned to adapt to several common desktop printers; a Marlin fork with native *ve-axis kinematics; a suite of browser-based tools that replace the command line and commercial licences with no-install work1ows for *rmware, setup, printer control, and G-code; and the documentation, website, and community that let someone actually build it, all released under GPLv3.
The system is evaluated through a pre-build survey, community-driven iteration, and independent build attempts. The *nding is that the barrier to multi-axis FDM isn’t the mechanism. It’s the toolchain and the infrastructure around it. Removing the specialist-so,ware dependency, packaging the work1ow for non-experts, and building a community where feedback drives the design are what turn a working prototype into something independent makers can reproduce.

# ACKNOWLEDGEMENTS

This thesis builds directly on the work of Janis Andersons, my supervisor, and wouldn’t exist without it. I’m grateful for that, but just as much for how welcome he made me feel from the start, gave me the room to take the project where it needed to go, and stayed genuinely interested in it the whole way through.
Rieks and Laura were in the lab with me almost every day for the past nine months. We each worked on our own project, but we sparred together and made sure none of us went crazy in the Horst. It made the long days a lot easier.
Thanks also to the members of the Rep5x Discord, who answered questions, gave input on the project, and were always up for a discussion. Some went further and contributed directly, and the project is better for it.
Finally, thanks to my girlfriend Eline, who dealt with me being a lot less available than I’d have liked. And to my friends and family, for putting up with me talking about nothing but 3D printers for the better part of a year.

# ABBREVIATIONS

AM | Additive manufacturing
API | Application programming interface
BOM | Bill of materials
CAD | Computer-aided design
CAM | Computer-aided manufacturing
CNC | Computer numerical control
COTS | Commercial o--the-shelf
CRM | Customer relationship management
DLP | Digital light processing
DoF | Degrees of freedom
DSR | Design Science Research
DSRM Design Science Research Methodology
FDM | Fused deposition modelling
FFF | Fused *lament fabrication
GPL | GNU General Public License
GUI | Graphical user interface
HH | Head-head (kinematic con*guration)
HT | Head-table (kinematic con*guration)
IK | Inverse kinematics
JSON | JavaScript Object Notation
LB | B-axis o-set: distance from the B-axis (tilt)
| rotation centre to the nozzle tip
LC | C-axis o-set: distance from the C-axis (yaw) rotation centre to the nozzle tip
NEMA | National Electrical Manufacturers Associa-
| tion (stepper frame size, e.g. NEMA 17)
OCL | Open Community Licence
OHL | CERN Open Hardware Licence
OSHW | Open-source hardware
OSHWA Open Source Hardware Association
OSS | Open-source so,ware
PETG | Polyethylene terephthalate glycol
PLA | Polylactic acid
RMS | Root mean square
SLA | Stereolithography
SLS | Selective laser sintering
SM | Subtractive manufacturing
STEP | Standard for the Exchange of Product model
| data
STL | Standard tessellation language (3D model
| *le format)
TT | Table-table (kinematic con*guration)
UART | Universal asynchronous receiver-transmitter
UI | User interface
UX | User experience

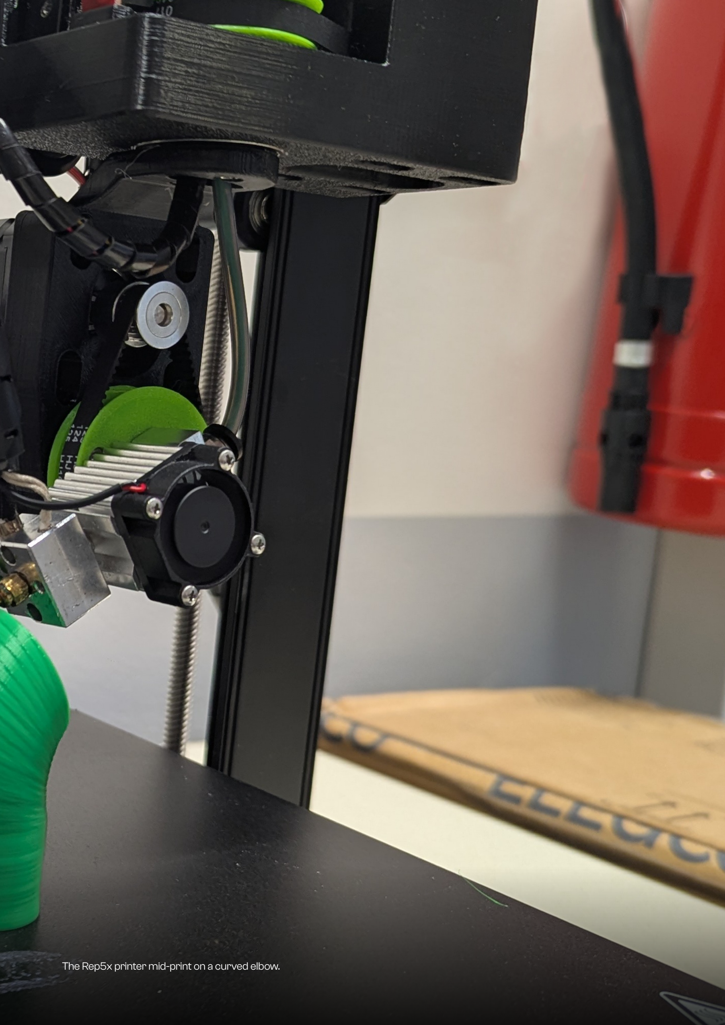
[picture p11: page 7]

The Rep5x printer mid-print on a curved elbow.

C H A P T E R 0 1
01

# INTRODUCTION

### This chapter covers the basics of additive manufacturing and FDM, the role of open-source hardware, the limitations of conventional FDM that multi-axis printing addresses, and the prior work by Andersons that this research builds

on. It closes with the problem statement, research questions, and scope.

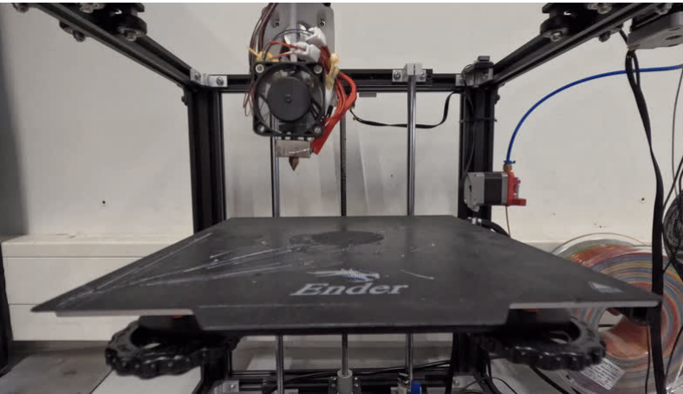
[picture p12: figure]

C H 0 1 I N T R O D U CT I O N | D E M O C R AT I S I N G M U LT I - A X I S 3 D P R I N T I N G

### Additive manufacturing has transformed from an expensive industrial process into something that everyone can use. Fused Deposition Modelling (FDM) printers can be bought for under €200, and FDM is the most popular AM

process [1]. But there are limitations.

These printers deposit material in 1at layers, one on top of the other, and this planar constraint causes well-known problems: support structures for overhanging geometry, visible staircase e-ects on curved surfaces, and mechanical weakness between layers. Multi-axis printing addresses all three by adding rotational degrees of freedom. Yet multi-axis printers aren’t widespread, remaining con*ned to research labs and industrial settings.
The problem isn’t that multi-axis printing doesn’t work. The problem is that the technology still isn’t accessible to the general public. The hardware is expensive, the so,ware requires specialist knowledge, and the documentation doesn’t exist. This thesis is about changing this. This chapter provides the background needed to understand the problem. It covers the basics of additive manufacturing and FDM, the role of open-source hardware in making technology accessible, the limitations of conventional FDM that multi-axis printing addresses, and the prior work by Andersons that this research builds on. It concludes with the problem statement, research questions, and scope.

### 1.1 BACKGROUND

Additive manufacturing
History and growth. Additive Manufacturing, generally known as 3D printing, is the process of fabricating a part layer by layer [1]. Material is added incrementally, in contrast to subtractive manufacturing (SM), where material is removed from a solid block. The *rst patent for what could be considered an AM technology was granted in 1971, for depositing molten metal through a nozzle onto a carrier. Developments on stereolithography (SLA) followed in the 1980s, when Charles Hull patented a tool for curing successive layers of photopolymer with UV light [2]. Within a few years, several additional AM processes were identi-*ed, now compartmentalised into seven general process categories by the ISO/ASTM 52900 standard [3]: material extrusion, vat photopolymerisation, powder bed fusion, material jetting, binder jetting, directed energy deposition, and sheet lamination.
S. Scott Crump invented Fused Deposition Modelling and patented it through Stratasys in 1992 [4], with the original mechanism shown in Fig. 1.1. For most of its history, AM was an industrial technology. Machines cost hundreds of thousands of euros and required trained operators. They were used primarily for rapid prototyping, making physical models to check designs before committing to expensive tooling.
That changed in the late 2000s. Stratasys’ FDM patent expired a,er its 20-year term around 2009. Combined with the rise of open-source hardware initiatives like RepRap [6], this made AM accessible to consumers. The AM industry has since grown into a multi-billion dollar market [1]. FDM has become the most commonly used

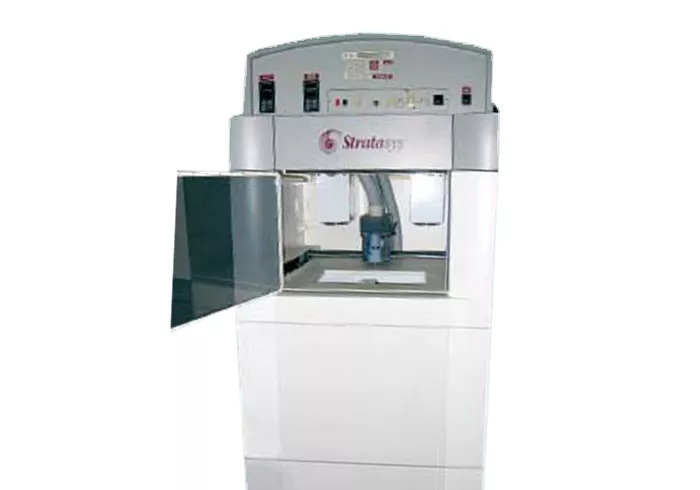
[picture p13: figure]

FIG.1.1 The origins of FDM: S. Scott Crump’s 1992 patent drawing [4], and the Stratasys 3D Modeler, the /rst commercial FDM machine [5].

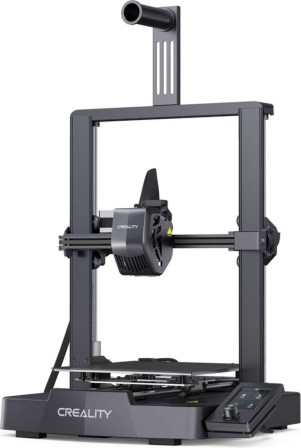
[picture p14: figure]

FIG.1.2 Three common consumer FDM printers: the Creality Ender 3 V3 SE [7], the Bambu Lab A1 mini [8], and the Prusa MK4S [9].

DENNIS KLAPPE · UNIVERSITY OF TWENTE | 9

C H 0 1 1 . 1 B A C KG R O U N D | D E M O C R AT I S I N G M U LT I - A X I S 3 D P R I N T I N G

process type, widely adopted for both prototyping and
end-use parts [1]. The current consumer landscape is
wide, with capable machines available from under €200
(Fig. 1.2).

### 1.2 FUSED DEPOSITION MODELLING

Working principles
Fused Deposition Modelling, or Fused Filament Fabrication (FFF) to avoid trademark issues with Stratasys, is an AM process based on material extrusion. A heated nozzle (the hot-end) melts a thermoplastic *lament and deposits it on a bed in thin beads, as shown in Fig. 1.3. The nozzle follows a predetermined path, completing one layer at a time. The bed (or nozzle) moves one layer height in the Z-direction once each layer is *nished, and the next layer is deposited on top of the previous one [1].
An FDM printer typically consists of three linear axes (X, Y, and Z), a heated bed, and an extruder. A slicer takes a 3D model (typically an STL *le), cuts it into horizontal layers, and generates G-code for the printer. Cura, PrusaSlicer, and OrcaSlicer are widely used open-source slicers.
FDM works with a range of thermoplastic materials. PLA (polylactic acid) is the most common for hobbyists due to its ease of printing. PETG, ABS, TPU, nylon, and carbon-*bre-reinforced composites are also widely used, each requiring di-erent print parameters for temperature, speed, cooling, and bed adhesion.
The open-source hardware movement
The RepRap project, initiated by Adrian Bowyer at the University of Bath (Fig. 1.4), made desktop 3D printing what it is today [10]. Today’s consumer FDM ecosystem, from the €150 Ender 3 to the Prusa MK4 to community-driven designs like the Voron Trident, descends directly from it. The assumption isn’t just that a design works, but that others can build it, change it, and contribute back. That’s the environment in which Rep5x operates. The development model itself, what makes open-source hardware reproducible (or not), and the projects that succeeded or failed at it, are reviewed in the literature review.

Limitations of conventional FDM
Conventional 3-axis FDM printers deposit material exclusively in 1at layers stacked along the Z-direction. This planar constraint leads to three well-known problems. Support structures. Overhanging geometry can’t be printed in mid-air. The slicer generates support structures under these features, which must be removed a,er printing. The commonly cited threshold is an overhang angle of approximately 45°, beyond which quality degrades and support material becomes necessary [12]. This wastes material, increases print time, and leaves surface marks where the supports were attached.
Staircase e ect. Curved and angled surfaces exhibit visible layer lines, known as the “staircase e-ect.” How pronounced it is depends on the layer height and the angle of the surface relative to the build direction. Smaller layer heights reduce the e-ect, but at the cost of proportionally longer print times [1].
Mechanical anisotropy. The bond between layers is weaker than the material within a layer. Zohdi et al. [13] report that mechanical anisotropy in FDM parts can reach nearly 50%, meaning the strength in the build direction can be roughly half of what it is in the XY plane (Fig. 1.5). This is the highest mechanical anisotropy among polymer AM methods, with comparable *gures of around 10% for SLS, 5% for DLP and 1% for SLA [13], caused primarily by insuScient interlayer bonding and air voids between deposited *laments. In a standard 3-axis printer, the layer orientation is always perpendicular to the Z-axis, meaning the part’s weakest direction is *xed regardless of where the loads are. There’s no way to align the layer direction with the stress distribution of the part.
These three limitations constrain what FDM can reliably produce. And they all stem from the same root cause: the restriction to planar deposition.

### 1.3 MULTI-AXIS PRINTING

Principles and bene>ts
Adding two rotational axes changes this. By tilting and rotating the part (or the nozzle) during printing, the direction of deposition can be adjusted dynamically. Rather than exclusively stacking horizontal layers, the printer can

FIG.1.3 Working principle of FDM: /lament is melted in the hot-end and deposited bead by bead, one layer at a time.

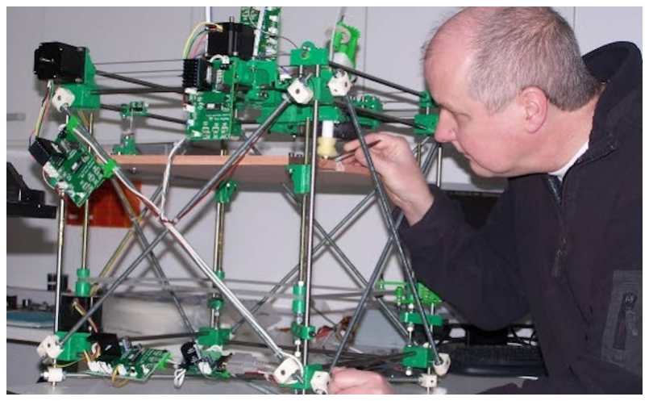
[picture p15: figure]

FIG.1.4 Adrian Bowyer, who initiated the RepRap project at the University of Bath [11].

DENNIS KLAPPE · UNIVERSITY OF TWENTE | 10

C H 0 1 1 . 3 M U LT I - A X I S P R I N T I N G | D E M O C R AT I S I N G M U LT I - A X I S 3 D P R I N T I N G

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
FIG.1.5 Mechanical anisotropy across polymer AM methods. FDM reaches roughly 50% (build-direction strength about half of in-plane strength), much higher than SLS, DLP, and SLA [13].
deposit material at varying angles [14]. This opens up three
possibilities.
Support-free printing. Overhangs that would normally require support can be printed directly by reorienting the part during printing. The nozzle approaches the surface from an angle where the overhang is no longer an overhang. This eliminates the material waste, time, and surface damage associated with support removal.
Improved surface quality. When the nozzle can follow curved surfaces rather than just horizontal passes, non-planar toolpaths can reduce or eliminate the staircase e-ect entirely, producing smoother surfaces without post-processing [14]. Fig. 1.7 shows an aerofoil printed with conformal layers that follow the surface curvature. Controlled anisotropy. By changing the build direction during printing, layers can be aligned with the expected stress distribution of the part. This directly addresses the anisotropy problem by making sure the weak interlayer bonds are oriented away from the primary load paths. Fig. 1.6 illustrates the di-erence. The same part printed with 3-axis planar layers requires support material under the overhang and shows visible staircase stepping on the curved surface. With 5-axis non-planar toolpaths, the layers follow the geometry, the overhang is printed directly by tilting the build direction, and no support is needed.

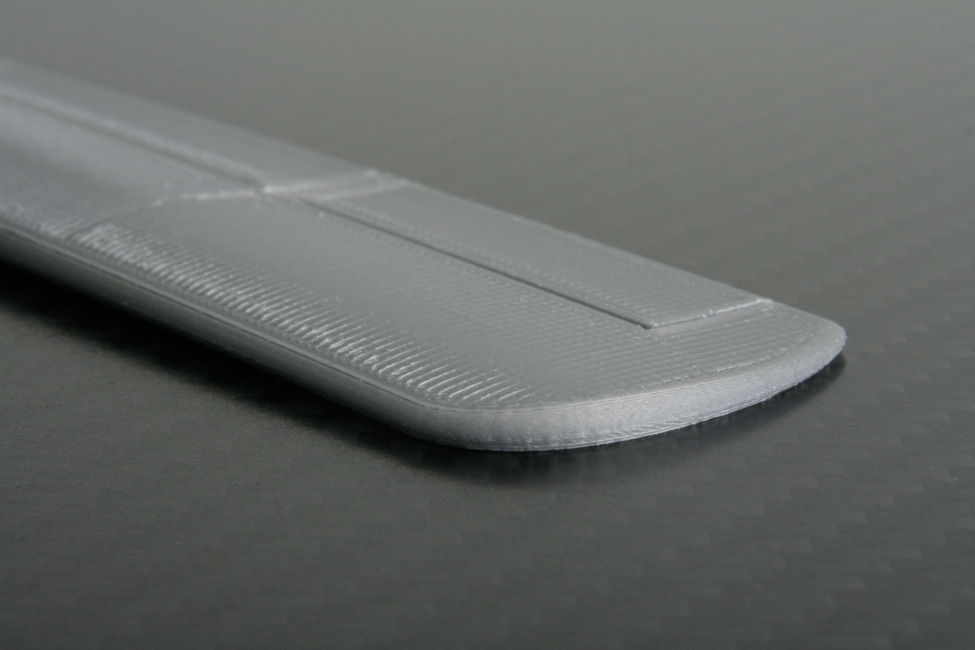
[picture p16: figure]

FIG.1.7 An aerofoil printed with non-planar layers conforming to the wing surface [15].
The trade-o- is complexity. Five-axis printing requires more advanced kinematics, more sophisticated toolpath planning, and calibration. But the bene*ts still make it worth the added complexity.
Current state
In industry, multi-axis AM isn’t new. Systems using robotic arms have been depositing material along non-planar paths for years. These systems typically use six-axis industrial robots with extrusion heads, intended for large-scale applications such as boat hulls, architectural components,

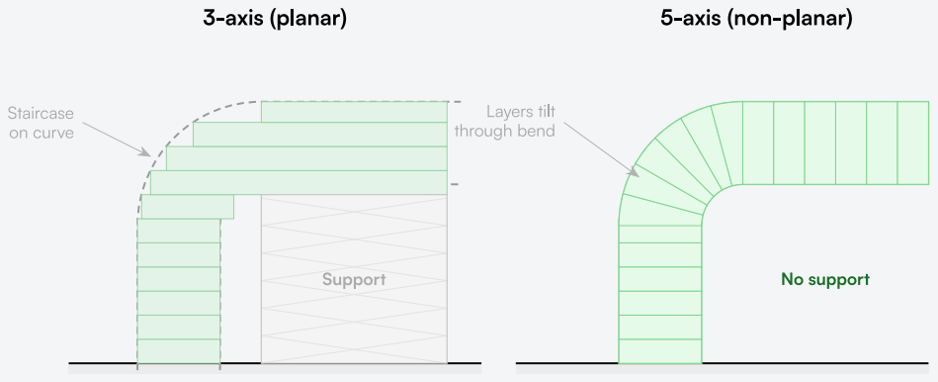
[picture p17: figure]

FIG.1.6 The same 90° bent tube printed with 3-axis planar layers (leE) and 5-axis conformal layers (right). Dashed lines show the intended tube pro/le.

DENNIS KLAPPE · UNIVERSITY OF TWENTE | 11

C H 0 1 1 . 3 M U LT I - A X I S P R I N T I N G | D E M O C R AT I S I N G M U LT I - A X I S 3 D P R I N T I N G

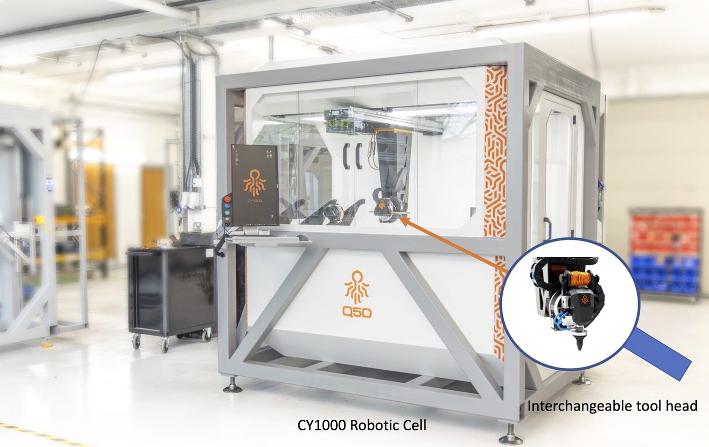
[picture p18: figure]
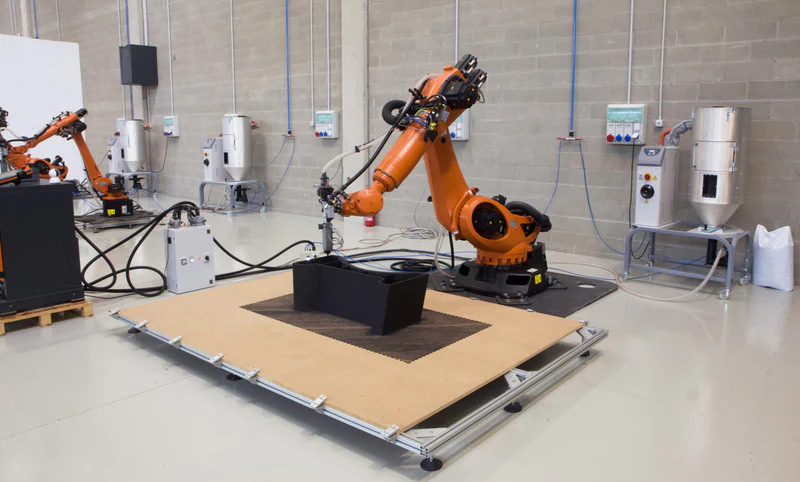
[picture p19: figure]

FIG.1.8 Industrial multi-axis AM: a Caracol industrial robotic-arm 3D printer [16] and Q5D’s CY1000 industrial 5-axis robotic cell [17].
or aerospace tooling (Fig. 1.8). Smaller industrial 5-axis
cells, like the Q5D CY1000, target wire-harness automation and aerospace electronics.
Research groups have explored di-erent kinematic con*gurations for desktop-scale multi-axis FDM. These are typically categorised into three groups based on where the two additional rotational axes are placed: head-head (HH), table-table (TT), and head-table (HT) [18]. Each has di-erent trade-o-s in workspace, complexity, and print quality; these are looked at in detail in the literature review. What’s missing is a solution that the average maker can actually use. Industrial systems cost tens of thousands of euros at minimum, require specialised so,ware, and target professional users. Research prototypes are built in university labs and work, but nobody else can reproduce them. There is no accessible path for a maker to explore multi-axis printing.
Barriers to adoption
Rogers [19] identi*es *ve attributes that determine whether a technology gets adopted: relative advantage, compatibility, complexity, trialability, and observability. Applying this framework to multi-axis FDM reveals that while the technical advantage is clear, the other four attributes are all problematic. Fig. 1.9 summarises *ve speci*c barriers that keep multi-axis printing from reaching the broader maker community: single-printer dependency, a so,ware gap (no consumer-grade slicer, commercial dependencies), calibration diSculty, missing documentation, and the absence of community infrastructure. Together they create a chicken-and-egg problem. Without accessible hardware, there’s no incentive to develop accessible so,-ware. Without accessible so,ware, there’s no motivation to build hardware. The framework behind these barriers is examined in detail in the literature review, and each barrier is broken down into concrete technical detail in the analysis of requirements.

FIG.1.9 Five adoption barriers identi/ed for multi-axis FDM.

### 1.4 PRIOR WORK

Andersons' 5-axis retro>t prototype
In 2023, Andersons [18] completed a master’s thesis at the University of Twente, supervised by the same research group that supervises this work. His thesis, “Exploring the benets and limitations of multi-axis 3D printing for improved part quality and reduced waste,” looked into whether a consumer FDM printer could be converted into a 5-axis system.
Andersons designed a retro*t mechanism that adds two rotational axes to a Creality Ender 5 Pro. His *nal design, called the “Robot Wrist 2” (RW2), uses a head-head (HH) con*guration: both rotational axes are placed at the nozzle, replacing the standard print head with a compact kinematic arrangement where the two axes intersect near the nozzle tip (Fig. 1.10). Andersons labels the yaw axis A and the tilt axis B. Rep5x re-labels the yaw axis as C to match standard 5-axis CNC conventions; the rationale is given in the design and development chapter. Throughout this thesis, Andersons’ axes are referred to as A and B, and Rep5x’s as C and B.
DENNIS KLAPPE · UNIVERSITY OF TWENTE | 12

C H 0 1 1 . 4 P R I O R W O R K | D E M O C R AT I S I N G M U LT I - A X I S 3 D P R I N T I N G

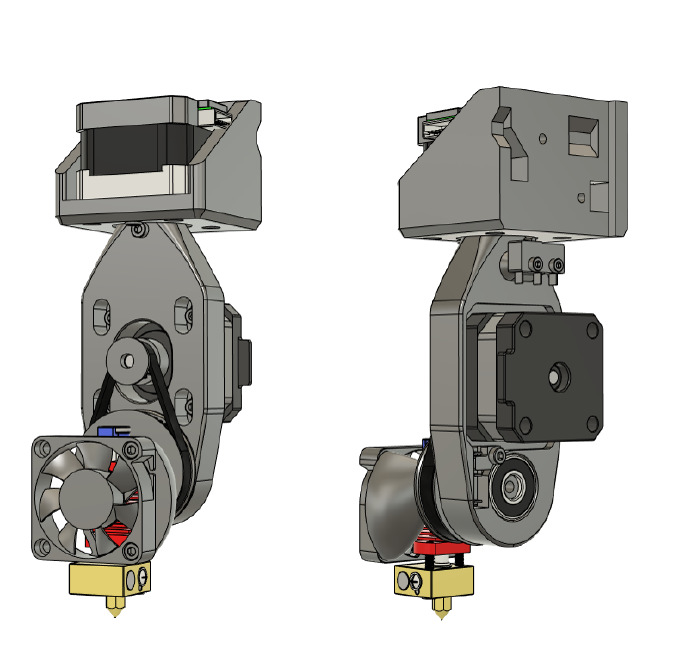
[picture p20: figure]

FIG.1.10 Head-head (HH) 5-axis con/guration: Andersons’ Robot Wrist 2, with both rotational axes placed at the print head and intersecting near the nozzle tip [18].
The retro*t was designed with accessibility as a goal. Structural parts were 3D printed, the motors are conventional NEMA 17 steppers, and the total BOM cost was kept under €150. Andersons used a modi*ed version of Marlin *rmware to support the extra axes and developed inverse kinematics formulas to translate 5-axis coordinates into machine movements [18].
Findings and contributions
Andersons demonstrated several important results. Overhanging geometry was printed without support material, including tube-shaped parts with curves through 90° of arc. Surface quality of non-planar samples was superior to planar equivalents, maintaining low roughness (19–30 µm Sa) across the full range of surface angles, whereas planar samples degraded to 114 µm Sa at shallow surface angles. Dimensional accuracy was validated through 3D scanning: the range of deviation for non-planar samples was comparable to, and in some cases lower than, that of planar samples. Waste reduction was substantial, with the most extreme test cases showing material and print-time reductions in excess of 80% and 90% respectively [18]. His thesis also included a detailed survey of multi-axis AM hardware, benchmark parts, and path-planning algorithms. That technical groundwork doesn’t need to be repeated here. The literature review takes a di-erent approach: rather than focusing on the engineering, it examines open-source hardware practices, technology adoption theory, and community-driven development, the areas that explain why working technology doesn’t get adopted and what it takes to change that.
On the so,ware side, Andersons built a toolchain using Grasshopper (a visual scripting plugin for Rhinoceros 3D) for non-planar slicing and a Python script as a translation layer for inverse kinematics and G-code post-processing. Calibration was performed using a dial gauge for Z-axis errors and a reference cone for XY errors, with sinusoidal error functions *tted to the measured data for so,ware compensation [18].
Remaining challenges
Andersons showed that the concept works. But by his own admission, the prototype was a *rst iteration, and several problems remained.
Reproducibility. The design was tested on a single printer in a university lab. There were no build guides, no assembly instructions, and no BOM formatted for independent reproduction. Anyone wanting to build the system would have to reverse-engineer it from the thesis. Antoniou et al. [20] surveyed 30 OSHW practitioners; 25 referred to documentation quality as a factor in project success. By that measure, and by the criteria of Bonvoisin et al. [21], the prototype simply wasn’t packaged for someone else to rebuild, which is the gap this work sets out to close.
So$ware accessibility. The Grasshopper work1ow requires a Rhinoceros 3D licence and experience with visual programming. The Python scripts were functional but not packaged in any user-friendly way.
Calibration complexity. The calibration process required precise instruments and did not have a 1ow of actually correcting the errors yet. This isn’t something that a typical maker can be expected to do.
Single-platform design. The retro*t was designed for and tested on the Ender 5 Pro exclusively. Adapting it to other printers would require mechanical redesign, but no guidelines or parametric design tools were provided.
No community infrastructure. There was no website, no documentation platform, and no community forum. The work existed in isolation as an academic thesis. These challenges don’t undermine Andersons’ work. Demonstrating that an a-ordable, open-source multi-axis retro*t is technically doable is a signi*cant result. But feasibility and accessibility aren’t the same thing. The gap between “a working prototype exists in a university lab” and “someone else can build one at home” is where this work begins.

### 1.5 PROBLEM STATEMENT

These remaining challenges aren’t independent. They group into three problem areas: reproducibility of the hardware build, accessibility of the so,ware work1ow, and the absence of a community around the project. Each reinforces the others. Without a build guide, no one rebuilds the system; without rebuilds, no community forms; without a community, no one writes accessible so,ware. The core problem is therefore one of democratisation: closing this loop, rather than *xing any single barrier, is what separates a working prototype from something makers can actually build.

### 1.6 RESEARCH OBJECTIVES

The main goal of this research is to redesign the multi-axis retro*t system so that it can be built by independent makers using parts that are a-ordable and easy to source.

DENNIS KLAPPE · UNIVERSITY OF TWENTE | 13

C H 0 1 1 . 6 R E S E A R C H O B J E CT I V E S | D E M O C R AT I S I N G M U LT I - A X I S 3 D P R I N T I N G

In addition to the hardware, a set of open-source tools
and documentation is developed, including so,ware tools,
build guides, part lists, and calibration procedures. The
result should be a complete system that guides a maker from building the hardware to producing multi-axis prints. Finally, the system is put in front of independent makers to reproduce, and their feedback is incorporated into the design.

### 1.7 RESEARCH QUESTIONS

The primary research question is:

How can a 5-axis retro t system be redesigned and documented so that independent makers can reproduce it?

This is broken down into the following sub-questions:

### 1. What factors in open-source hardware development

and technology adoption determine whether a project is successfully reproduced by independent makers?

### 2. What so,ware tools, documentation, and community

infrastructure are needed for successful replication by makers without specialist knowledge?

### 3. How can community feedback be gathered and

analysed to inform and iteratively improve the system?

### 1.8 SCOPE AND BOUNDARIES

This research aims to make 5-axis printing more accessible for the maker community, not to develop new printing technology. No novel kinematic concept or new slicing algorithm is being invented. Rather, a proven concept is being made reproducible. The contribution lies not in the technology itself, but in its democratisation.
Target audience
The intended audience is makers with basic knowledge of 3D printing and electronics. Not experts, but not complete beginners either. The assumption is that the builder owns or has access to a working FDM printer, is comfortable with basic wiring and soldering, and can follow detailed but non-trivial instructions. This is roughly the demographic that builds Voron printers or assembles Prusa kits: technically engaged hobbyists who enjoy the build process.
Budget constraints
The design should be a-ordable. The target is to keep the total cost of the retro*t, excluding the base printer and standard tools, under €200. This is in line with Andersons’ original BOM cost of roughly €150 and keeps the system accessible to hobbyists.
Technical boundaries
This research doesn’t aim to create entirely new slicing so,ware or build *rmware from scratch. Instead, it builds on existing tools and work1ows, especially the Marlin

*rmware ecosystem. The focus is on the FDM process; other AM technologies such as SLA and SLS are outside scope. Industrial applications, certi*cation, and commercialisation are also not addressed. The goal is a functional, well-documented, open-source system for personal and educational use.
The Creality Ender 3 V3 SE and Ender 5 Pro serve as the primary development platforms because they are widespread and a-ordable. But the design is explicitly intended to be adaptable to other printers, and community guidelines are provided for this purpose.

### 1.9 THESIS OUTLINE

The remainder of this thesis is structured as follows.
The literature review reviews the literature across three areas: the technical landscape of multi-axis FDM (building brie1y on Andersons’ research), open-source hardware development practices and what makes projects reproducible, and technology adoption theory using Rogers’ di-usion of innovations framework. The emphasis is on adoption and accessibility rather than the technical foundations, which Andersons already covered in depth. The methodology chapter describes the research methodology, including the design approach, the user validation strategy, and the tools employed throughout this work.
The analysis chapter presents the analysis of requirements, both functional and non-functional, that the redesigned system must satisfy.
The design and development chapter details the design and development of the Rep5x system: the hardware and the browser-based so,ware tools.
The evaluation chapter presents the evaluation of the system through independent builder tests and community feedback.
The discussion chapter provides a discussion of the results, re1ecting on what worked, what didn’t, and what the *ndings mean for the *eld.
Finally, the conclusion draws conclusions and identi*es directions for future work.
DENNIS KLAPPE · UNIVERSITY OF TWENTE | 14

02

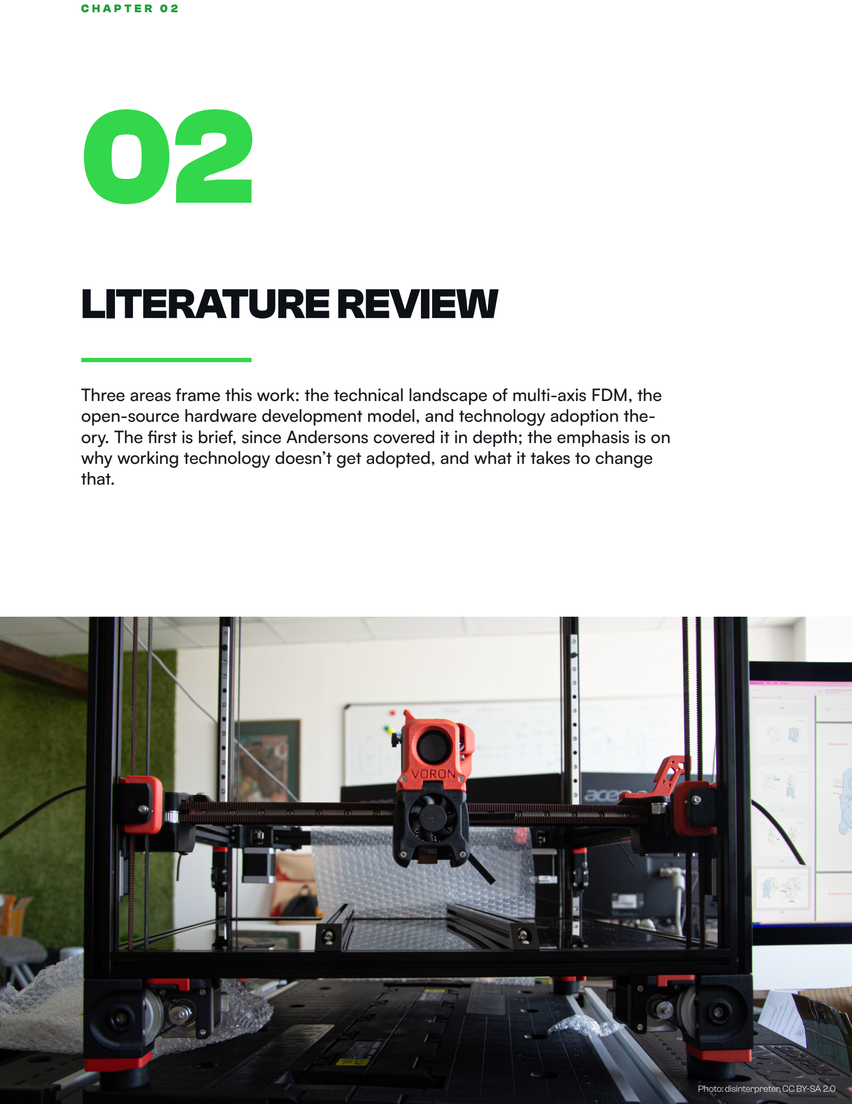
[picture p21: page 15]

C H A P T E R 0 2

# LITERATURE REVIEW

### Three areas frame this work: the technical landscape of multi-axis FDM, the open-source hardware development model, and technology adoption theory. The .rst is brief, since Andersons covered it in depth; the emphasis is on why working technology doesn’t get adopted, and what it takes to change

that.

Photo: disinterpreter, CC BY-SA 2.0

C H 0 2 L I T E R AT U R E R E V I E W | D E M O C R AT I S I N G M U LT I - A X I S 3 D P R I N T IN G

The technical landscape comes *rst and shortest: Andersons [18] already documented it, so the focus here is
what’s changed since 2023. The open-source hardware
section asks what makes a hardware project reproducible, drawing on the RepRap legacy and the wider maker community. The technology adoption section then turns to Rogers’ di-usion of innovations as its analytical lens.

### 2.1 MULTI-AXIS ADDITIVE

MANUFACTURING

Kinematic con>gurations
Multi-axis FDM systems extend the three linear axes of a conventional printer with two additional rotational axes, providing the 5 Degrees of Freedom (DoF) needed for non-planar deposition. Only 5 DoF are required because the nozzle output is rotationally symmetric, making a 6th axis redundant [18].¹ The two additional axes can be placed at the print head, the build plate, or split between them, producing three common categories: head-head (HH), table-table (TT), and head-table (HT) [18].
Industrial systems typically use 6-DoF robotic arms [14], which are versatile but expensive. As Andersons [18] puts it, they’re “too expensive to be adopted in the consumer or prosumer AM market.” For consumer-scale multi-axis printing, a more practical approach is the 3+2 con*guration: a conventional 3-axis printer combined with a separate 2-axis mechanism [14], the same idea as adding a rotary table to a 3-axis CNC mill.
Andersons [18] provides a detailed comparison of TT, HH, and HT con*gurations. The key trade-o-s: TT con*gurations keep the nozzle gravity-aligned but add mass to the bed and reduce build volume. HH con*gurations preserve build volume but introduce *lament routing constraints and add mass to the gantry. HT splits the axes as a compromise. Each has been demonstrated in research prototypes, including the Open5x TT retro*t for the Prusa i3 MK3s [22] (Fig. 2.1), a variant by a community maker for Voron-style printers, and the Pentaxis HH retro*t [18].

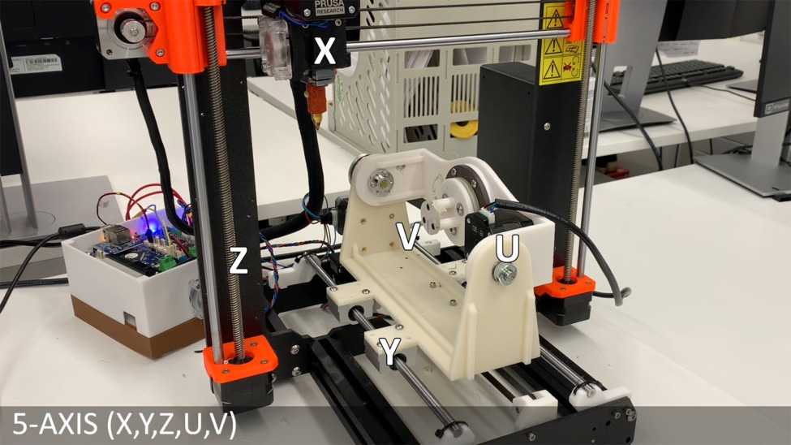
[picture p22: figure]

FIG.2.1 The Open5x table-table 5-axis retro/t mounted on a Prusa i3 MK3s. Source: Hong et al. [22].
Multi-axis printing also introduces an interference problem that doesn’t exist in conventional FDM. When the build plate or nozzle tilts, the part being printed can collide

¹This wouldn’t hold for non-circular nozzle geometries, which have been explored in some research.

with the hot-end assembly. In planar printing, the 1at-layer approach guarantees that no part geometry is ever higher than the nozzle tip. That guarantee disappears with non-planar motion [18]. Several solutions have been proposed, from extended nozzles with heat-insulating sleeves to slim-pro*le hot-ends that replace the conventional bulky heat block entirely, all trading thermal performance for clearance [18].
Path-planning and slicing
Conventional slicers cut a part into 1at cross-sections along the Z-axis. To use the additional degrees of freedom in multi-axis FDM, parts need to be sliced di-erently, and the toolpath generation algorithms are considerably more complex [14]. Andersons [18] identi*es three main approaches.
Feature-based decomposition treats di-erent regions of a part as separate structures, each printed with its own build direction. An overhanging feature is printed in a direction where the overhang is no longer problematic, using a previously printed surface as its e-ective build plate. The main challenge is automatically decomposing complex geometry into printable sub-volumes [14]. Conformal slicing generates curved layers that follow the geometry of the part, using iso-surfaces of a scalar *eld rather than planar cross-sections. This is e-ective for reducing the staircase e-ect on curved surfaces. Dai et al. [23] demonstrated this for support-free volume printing using a 6-DoF robotic arm. Andersons [18] used a conformal approach implemented in Grasshopper, a visual scripting plugin for the commercial CAD package Rhino. The RotBot’s conical slicing is a speci*c variant that uses only 4 axes, trading generality for simplicity [18].
G-code transformation avoids multi-axis slicing entirely. The part is sliced conventionally using a standard slicer, and the resulting G-code is mathematically transformed to include rotational axis commands. This uses the already mature toolpath generation of existing slicers (retraction, in*ll patterns, speed control) rather than reimplementing it from scratch. The downside is that the transformed toolpaths aren’t aware of multi-axis constraints during generation, which can lead to collisions or suboptimal deposition angles.
Calibration and error compensation
Adding rotational axes introduces geometric errors that don’t exist in conventional planar systems. The important parameters are the o-sets between the rotational axes and the nozzle tip. In an HH con*guration, these are the distances from the nozzle tip to the yaw rotation centre, and from the nozzle tip to the tilt rotation centre. Small errors in these o-set values show through the inverse kinematics calculations, producing dimensional errors that increase with tilt angle. Additional error sources include axis misalignment, backlash in rotary mechanisms, and eccentricity in rotation [18].
Andersons [18] measured these errors by actuating the rotational axis in increments and recording the deviation at each position, using a dial gauge for Z-axis errors
DENNIS KLAPPE · UNIVERSITY OF TWENTE | 16

C H 0 2 2 . 1 M U LT I - A X I S A D D I T I V E M A N U FA CT U R I N G | D E M O C R AT I S I N G M U LT I - A X I S 3 D P R I N T I N G

and a reference cone for XY errors. The process is timeconsuming and requires some skill, but doesn’t need
specialised equipment. Industrial 5-axis CNC uses more
sophisticated methods (touch probes, laser interferometry, ball-bar testing), but these aren’t practical for desktop printers. A middle ground is needed: good enough to produce quality prints, simple enough for a non-expert to perform.
Even a,er physical calibration, residual errors remain that vary periodically across the rotation range. Andersons
[18] *tted sinusoidal error functions to measured data points, transforming a mechanical calibration problem into a so,ware compensation problem. This is important for accessibility: the user doesn’t need perfect mechanical alignment, just enough measurements for the so,ware to correct the remaining errors.
Firmware and inverse kinematics
When rotational axes are added to an FDM printer, the G-code speci*es the desired nozzle position and orientation, but the *rmware must calculate where the physical motors need to move. Rotating the build plate around a pivot point displaces the workpiece relative to the nozzle, and the *rmware (or a pre-processing step) must compensate for this displacement [18].
Neither Marlin nor Klipper, the two big open-source FDM *rmware platforms, has native support for 5-axis FDM kinematics. Andersons [18] handled inverse kinematics as a pre-processing step in a Python script. This works, but it tightly couples the so,ware pipeline to the printer’s kinematic parameters. Changes to the physical machine require regenerating the entire toolpath, not just updating a *rmware parameter. An alternative is to implement inverse kinematics directly in the *rmware, so the printer accepts standard 5-axis G-code and internally computes motor positions. This makes the system more modular and enables real-time calibration corrections.
Recent developments
Several developments in multi-axis AM have appeared since Andersons’ 2023 thesis. Two reviews of the *eld were published in 2024: Tang et al. [14] and Yao et al. [24] both catalogue the limitations of 3-axis AM, the potential of multi-axis approaches, and current implementation methods. Tang notes that “current multi-axis AM systems use robot arms extensively for manufacturing,” with toolchain standardisation between robots and CAD systems still an open problem [14]. Yao identi*es recurring issues around strength, anisotropy, and the fabrication of large-scale structures [24].
On the hardware side, parallel academic work has begun targeting accessibility directly. Cocco et al. [25], in a 2025 paper titled “Towards Accessible Non-Planar FFF”, demonstrate non-planar FFF on a commercially available RatRig V-Core 3.1 modi*ed with three independently actuated Z-axes, allowing the bed to tilt up to 30° during printing (shown in Fig. 2.2). The authors describe the modi*cation as requiring “only simple extensions to the rails and bed screws,” and release an open-source Python implementation that maps 3D toolpaths to machine commands. The motivation parallels this thesis: bring non-planar FFF within reach of the maker community without a robotic arm or custom-built hardware.
On the commercial side, Fractal Robotics released the Fractal 5 Pro [26], an open-source (GPLv3) benchtop 5-axis FDM printer with a CoreXY motion system inspired by the Voron Trident, accompanied by a custom 5-axis slicer (Fractal Cortex). The project’s bill of materials totals roughly USD 1,900 for a self-build.
What remains absent is a complete, documented, open-source system that combines accessible hardware, user-facing so,ware tools, and community infrastructure. Individual pieces exist, but none o-er the full stack needed for a non-expert to go from owning a desktop printer to producing multi-axis prints. Fig. 2.3 shows the existing multi-axis FDM systems referenced throughout this thesis, and Appendix B provides a detailed comparison of each. Appendix C looks at the available slicing and toolpath tools. The pattern across both is consistent: no existing project supports multiple printer platforms, so,ware accessibility is poor (requiring either commercial Rhino/ Grasshopper licences or Python scripting knowledge),

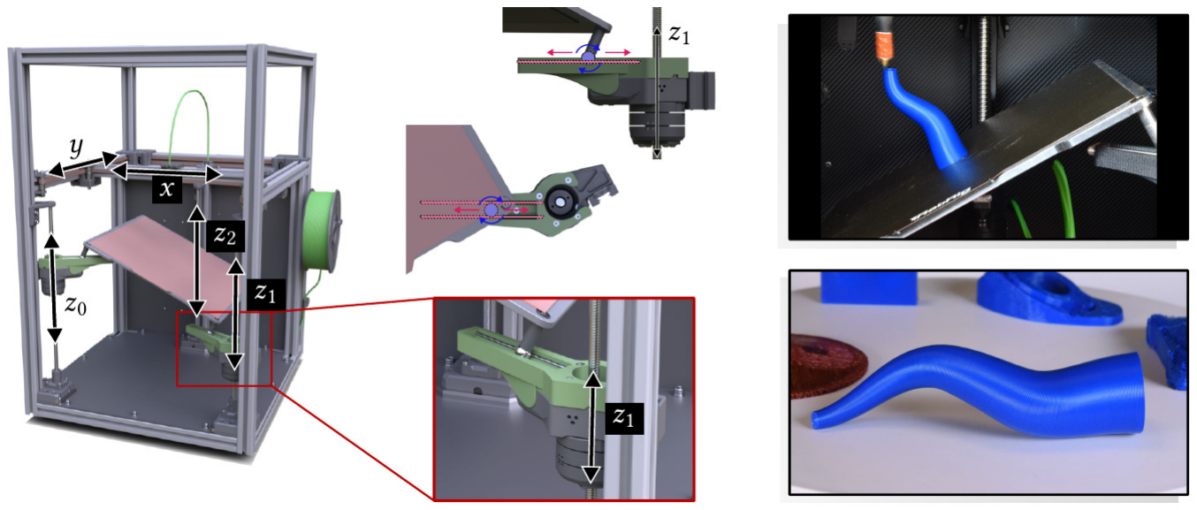
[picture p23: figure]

FIG.2.2 Cocco et al.‘s triple-Z modi/cation of the RatRig V-Core 3.1, tilting the bed up to 30° for non-planar deposition [25].

DENNIS KLAPPE · UNIVERSITY OF TWENTE | 17

C H 0 2 2 . 1 M U LT I - A X I S A D D I T I V E M A N U FA CT U R I N G | D E M O C R AT I S I N G M U LT I - A X I S 3 D P R I N T I N G
OPEN5X | ROTBOT | PENTAXIS
FRACTAL 5 PRO | VORON 5-AXIS | FULLCONTROL 4-AXIS

FIG.2.3 Existing multi-axis FDM systems referenced throughout this thesis, leE to right: Open5x [22], RotBot [27], Pentaxis [28], Fractal 5 Pro [26], Voron 5-axis [29], and FullControl 4-axis [30]. Appendix B gives a full comparison.
documentation rarely extends beyond a research paper,
and none has built a community for ongoing builder support. The gap isn’t any single barrier; it’s that no project addresses all of them together.

### 2.2 OPEN-SOURCE HARDWARE AND

THE MAKER ECOSYSTEM
Technical capability alone doesn’t drive adoption. The history of consumer 3D printing shows that what matters equally is the development model: how hardware is designed, shared, documented, and reproduced. This section examines the open-source hardware movement and its relevance to making multi-axis printing accessible. The RepRap project and its legacy
The RepRap project, initiated by Adrian Bowyer at the University of Bath, is what launched consumer 3D printing. The project’s goal was to create a 3D printer that could manufacture a large fraction of its own parts, enabling exponential growth through self-replication [10]. The RepRap machine achieved self-replication of 48% of its parts by count, ignoring fasteners such as nuts, bolts, and washers [6]. The remaining components were standard commercial o--the-shelf (COTS) items available from hardware suppliers.
The timing was important. Stratasys held a patent on Fused Deposition Modelling (US5121329, *led 1989), and the RepRap community coined the term “Fused Filament Fabrication” (FFF) speci*cally to provide a synonym that could be “used by all unrestrictedly” [6]. Several companies formed to sell machines inspired by RepRap, including MakerBot Industries in the United States and Bits From Bytes in the United Kingdom [6]. Their RepRapderived designs were distributed as free and open-source, as required by the GPL.

What made RepRap successful wasn’t just the hardware. It was the development model. The project was entirely open-source, with designs shared freely under the GPL licence. Contributors could modify designs and share improvements using the same printer they were improving. Jones et al. [6] describe how the *rst child RepRap, built from parts made by its parent, immediately printed a timing-belt tensioner as its very *rst part, a “grandchild” component for the next generation. This capacity for a machine to produce parts for its own copies is unique to self-replicating open-source hardware. Fig. 2.4 shows a typical Prusa Mendel RepRap with a self-printed *lament spool, illustrating the principle.

DENNIS KLAPPE · UNIVERSITY OF TWENTE | 18

C H 0 2 2 . 2 O P E N - S O U R C E H A R D WA R E A N D T H E M A K E R
E C O SYS T E M | D E M O C R AT I S I N G M U LT I - A X I S 3 D P R I N T I N G

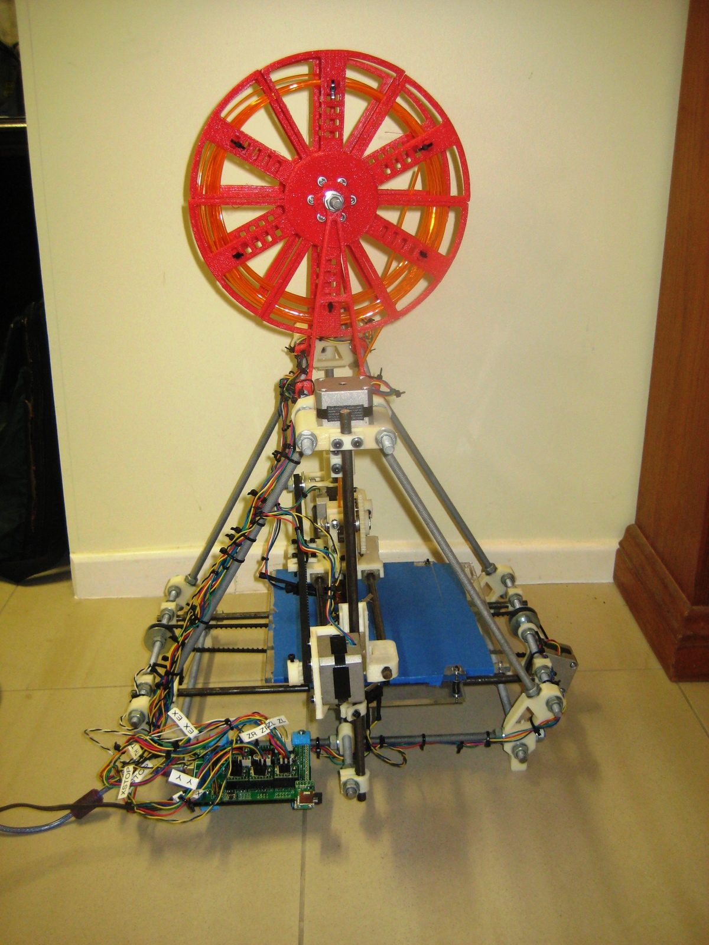
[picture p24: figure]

FIG.2.4 A Prusa Mendel RepRap with a self-printed /lament spool [31].
Pearce [32] argued that combining 3D printing with open-source microcontrollers (Arduino) running free so,ware enables the creation of scienti*c equipment at a fraction of proprietary costs. Wittbrodt et al. [33] quanti*ed this: households with open-source 3D printers achieve cost savings of $300-$2000 per year, with a simple payback period of 4 months to 2 years. The economic case for distributed manufacturing with open-source hardware is clear.
Open-source hardware principles Open-source hardware (OSHW) borrows its philosophical framework from open-source so,ware, but the translation isn’t straightforward. So,ware can be copied at zero marginal cost. Hardware can’t. Every reproduction of a physical design requires materials, tools, and labour. This fundamental di-erence means that “open” in the hardware context requires more than just publishing source *les.
Licensing and intellectual property. The Open Source Hardware Association (OSHWA) de*nes open-source hardware as “hardware whose design is made publicly available so that anyone can study, modify, distribute, make, and sell the design or hardware based on that design.” Several licences have been developed speci*cally for hardware: the CERN Open Hardware Licence (OHL), Creative Commons for documentation, and the GPL for *rmware and so,ware components. The choice of licence a-ects what downstream users can do with the design, particularly whether modi*cations must also be shared (copyle,) or not (permissive).

In practice, many projects that call themselves open-source don’t meet even basic criteria for openness. Bonvoisin et al. [34] analysed the public documentation of 132 OSHW products and found that practitioners interpret “open source” inconsistently. Many projects share only a fraction of the information needed for reproduction. Whether a project is truly open depends not just on licensing but on the completeness of shared design documentation: CAD *les, BOMs, assembly instructions, and *rmware source code. Only 17% (22/132) of the products in their sample satis*ed all four composite criteria of openness (transparency, accessibility, replicability, and commercial usability), and just 11% achieved the maximum openness score on the eight-criterion scale.
The challenge isn’t unique to 3D printing. Oellermann et al. [35] review how open electronics in scienti*c research can improve reproducibility and democratise access to instrumentation, though they note practical barriers including limited documentation, poor awareness, and community fragmentation. Oberloier and Pearce [36] propose a systematic design procedure for free and open-source hardware for scienti*c equipment, reporting cost reductions of 90-99% compared to proprietary equivalents and emphasising that documentation must be maintained alongside the design from the start, not bolted on as an a,erthought.
Self-replication and distributed development. The concept of self-replication in 3D printing extends beyond the RepRap project’s original vision. When a printer can manufacture parts for copies of itself, it enables a fundamentally di-erent development model. New hardware improvements can be pushed to existing users: a user with an older printer can print the parts for an upgrade, or even the parts for an entirely new machine. This development model has no real precedent outside 3D printing.
For multi-axis printing, self-replication is particularly relevant. The additional mechanical components needed to convert a 3-axis printer to a 5-axis system can themselves be 3D printed. This means an existing printer can bootstrap the hardware needed for its own upgrade. The Open5x project demonstrated this principle: most parts of the rotary table assembly are 3D-printable [22]. But self-replication only works if the printed parts are designed to be printable on the source machine. Large parts that approach the build volume limits, or parts requiring support structures that are diScult to remove, undermine the self-replication potential.
Design for reproduction
Publishing CAD *les isn’t enough to make a hardware project reproducible. The design itself must be engineered for reproduction by people with varying skill levels and access to di-erent tools and materials.
Design for manufacturability in open-source projects. Bonvoisin et al. [21] developed the Open-o-Meter (Fig. 2.5), a tool for measuring how “open” a hardware project actually is. Their eight criteria include: an OSHcompatible licence, design *les, a BOM, assembly instructions, original editable *les, a version control system, a
DENNIS KLAPPE · UNIVERSITY OF TWENTE | 19

C H 0 2 2 . 2 O P E N - S O U R C E H A R D WA R E A N D T H E M A K E R
E C O SYS T E M | D E M O C R AT I S I N G M U LT I - A X I S 3 D P R I N T I N G


FIG.2.5 The Open-o-Meter criteria for measuring hardware openness [21]. Most OSHW projects satisfy only a subset of these criteria.
contribution guide, and issue tracking. Most projects fail
on several of these criteria. The Open-o-Meter makes
explicit what many OSHW practitioners implicitly understand: openness is a spectrum, and most projects fall short of full openness.
Sells et al. [37] demonstrate that the combination of self-replication and open design maximises customisability, since users can modify and fabricate improvements using the same machine. This principle extends naturally to retro*t systems: an existing printer can produce the parts needed for its own multi-axis upgrade.
For 3D-printed hardware speci*cally, design for manufacturability means designing parts that print reliably on common consumer printers. This includes: avoiding excessive overhangs that require support material, keeping part dimensions within typical build volumes (roughly 180×180×180 mm), using common materials (PLA, PETG), and minimising the need for post-processing. Bills of materials and sourcing strategies. A complete and accurate BOM is essential for reproduction. But a BOM is only useful if the listed components are actually available to the builder. Projects that specify custom-machined parts, obscure electronic components, or region-speci*c suppliers create barriers to reproduction. The most reproducible OSHW projects use globally available COTS components: standard metric fasteners, common stepper motors (NEMA 17), widely available controller boards (Arduino, STM32-based), and standard bearings. When a project speci*es a component that’s only available from a single supplier, it creates a fragile dependency. Success factors and failure modes
Antoniou et al. [20] surveyed 30 OSHW practitioners to identify what makes projects succeed. Three themes emerged: value creation (the big-picture impact), quality of output (the quality of hardware and accompanying documentation), and e-ective processes (the activities that contribute to success). Successful projects create hardware that is “performant and highly accessible, reproducible and modi*able.” Documentation quality was referred to by 25 of 30 respondents as a factor in project success.
The most successful OSHW projects, like Arduino and the Prusa i3, share certain characteristics: active community engagement, documentation maintained alongside the hardware, economic sustainability (Arduino through board sales, Prusa through commercial sales of kits and assembled printers), and a design that’s genuinely reproducible without the original developer’s involvement. The failure mode is the opposite: a project published as “open source” with minimal documentation, no community, and designs that only the original developer can reproduce. Bonvoisin et al. [34] found that most self-described OSHW projects occupy a middle ground of partial openness, with a mean openness index of 4.2 across eight binary criteria. Only 17% satis*ed all four composite criteria (transparency, accessibility, replicability, commercial usability).

2.3 TECHNOLOGY ADOPTION,
ACCESSIBILITY, AND COMMUNITY
The *rst two sections of this chapter address the what: the technical landscape of multi-axis AM and the open-source development model. This section addresses the how: the mechanisms by which a niche technology reaches a broader audience.
DiEusion of innovations
The canonical framework for technology adoption is Rogers [19], who identi*es *ve attributes of an innovation that determine its rate of adoption: relative advantage (is it better than what it replaces?), compatibility (does it *t existing practices?), complexity (how hard is it to understand and use?), trialability (can potential adopters experiment with it?), and observability (can the results be seen by others?). These *ve attributes account for 49– 87% of adoption variation across studies.
Applying this to multi-axis FDM is instructive. The relative advantage is well established: reduced support material, improved surface quality, controlled anisotropy.
DENNIS KLAPPE · UNIVERSITY OF TWENTE | 20

C H 0 2 2 . 3 T E C H N O LO GY A D O P T I O N , A C C E S S I B I L I T Y, A N D
C O M M U N I T Y | D E M O C R AT I S I N G M U LT I - A X I S 3 D P R I N T I N G


FIG.2.6 Rogers’ adopter categories and the diKusion S-curve [19].
But the remaining four attributes are all problematic. Multi-axis printing isn’t compatible with existing work1ows; it requires di-erent slicers, di-erent *rmware, and modi*ed hardware. It scores poorly on complexity; the learning curve is steep. Trialability is near zero because there’s no easy way to experiment with multi-axis printing without *rst building or buying specialised hardware. And observability is limited because so few people have working systems that the results aren’t visible to the broader community.
Rogers also describes the adoption curve (Fig. 2.6): innovators (2.5%), early adopters (13.5%), early majority (34%), late majority (34%), and laggards (16%). Multi-axis FDM is currently at the innovator stage, con*ned to researchers and a small number of dedicated makers. Crossing the chasm to the early adopter stage requires lowering the barriers across all *ve of Rogers’ attributes.
DENNIS KLAPPE · UNIVERSITY OF TWENTE | 21

# The gap isn’t in what multi-axis printing can do. It’s in who can

do it.

DIFFUSION OF INNOVATIONS, APPLIED TO MULTI-AXIS FDM

“

T H E A D O P T I O N G A P
Rogers’ *ve attributes explain why a working technology stalls. For multi-axis FDM the relative advantage is strong, but compatibility, complexity, trialability and observability all remain unresolved [19]. And only 17% of open-source hardware projects meet full openness criteria [34], so even published designs are rarely reproduced.

C H 0 2 2 . 3 T E C H N O LO GY A D O P T I O N , A C C E S S I B I L I T Y, A N D
C O M M U N I T Y | D E M O C R AT I S I N G M U LT I - A X I S 3 D P R I N T I N G

Barriers to adoption in niche manufacturing
Hardware cost and complexity. The most obvious barrier
is the hardware itself. Industrial multi-axis AM systems
(robotic arms, custom 5-axis platforms) cost tens of thousands of euros. Commercial o--the-shelf 5-axis FDM machines do exist. VSHAPER’s 5AX is marketed to industrial customers in the automotive, aerospace, and medical sectors [38], and the 5AXISMAKER hybrid launched as the “*rst a-ordable 5-axis multi-fabricator” at around $5,000 [39]. But both sit well above the €200–500 range typical for consumer FDM. Even DIY approaches like Open5x require a compatible base printer, electronic components, and a substantial time investment for assembly. The additional mechanical complexity of multi-axis systems is itself a barrier, as the challenges catalogued by Tang et al. [14] illustrate. Each additional axis introduces new sources of error, requires additional motors and other components, and makes the system harder to assemble, calibrate, and maintain.
The cost barrier isn’t just *nancial. It’s also a barrier of e-ort. A maker who wants to try multi-axis printing must *rst get or build the hardware, learn how to calibrate it, *nd or create compatible slicing so,ware, and troubleshoot the inevitable problems that arise when combining modi*ed hardware with *rmware that wasn’t designed for it. The total e-ort required is orders of magnitude greater than setting up a conventional 3-axis printer, which typically works out of the box.
So$ware ecosystems and tool accessibility. Even when the hardware exists, the so,ware ecosystem for multi-axis FDM is fragmented and inaccessible. The two closest peers that ship both hardware and so,ware, Andersons’ retro*t [18] and Open5x [22], both rely on Grasshopper (a visual programming plugin for Rhino, a commercial CAD package) for conformal slicing and G-code generation. This stack works, but it requires: a Rhino licence, familiarity with visual programming, knowledge of the speci*c Grasshopper components, and an understanding of the underlying mathematics. The Open5x authors themselves acknowledge the constraint: “this dependency on a commercial product means that our solution is not completely open source” [22].
The contrast with conventional 3D printing is big. A user buying a new FDM printer today can download a free slicer, import an STL *le, click “slice,” and start printing within minutes. No comparable experience exists for multi-axis printing. The so,ware tools that do exist are scattered across research papers, GitHub repositories, and individual makers’ personal projects, with no uni*ed work1ow.
Knowledge gaps and documentation. The knowledge required to build and operate a multi-axis printer spans mechanical design, electronics, *rmware con*guration, slicing algorithms, inverse kinematics, and calibration. No single resource covers all of these in the context of consumer-grade multi-axis FDM. Research papers present results but rarely provide step-by-step build instructions. Maker projects on forums and YouTube show results but o,en lack the technical depth needed to replicate the work from scratch. Builders are le, to piece together understanding from disparate sources, which scales poorly: each new builder repeats the discovery process the previous one already went through.
Documentation as a design problem
Build guides and instructional design. A build guide isn’t just a list of steps. It needs to anticipate where builders will make mistakes, provide visual references for ambiguous assembly steps, and explain the why behind design decisions so that builders can troubleshoot when things go wrong. The most successful OSHW projects (Prusa, Voron) treat documentation as a *rst-class deliverable alongside the hardware and so,ware. A mediocre design with great documentation gets reproduced more successfully than a brilliant design with poor documentation.
Web-based tools and no-install so$ware. A real barrier to tool adoption is the installation and con*guration overhead. Desktop applications require downloading, installing, resolving dependencies, and o,en purchasing licences. Browser-based tools eliminate this entirely: the user opens a URL and the tool is ready to use. The Web Serial API, available as an origin trial from Chrome 78 (2019) and shipped as stable in Chrome 89 (March 2021), extends this to hardware communication, letting a web page read from and write to serial devices such as 3D printers and microcontroller boards.
This shi, is particularly relevant for niche hardware like multi-axis printers, where the target audience is already juggling hardware assembly, new concepts, and mechanical troubleshooting. A tool that runs in any modern browser, with no installation and a guided interface, has a fundamentally lower barrier to entry than any desktop application.
Community-driven development
Community as infrastructure. Von Hippel [40] established that users of products increasingly innovate for themselves, and that user innovation communities enable distributed, collaborative development. In the 3D printing space, this is obvious: the entire consumer FDM ecosystem was built by user-innovators, from the RepRap project to the Klipper *rmware to the Voron printer. Communities on Discord, Reddit, GitHub, and dedicated forums serve as infrastructure: they provide channels for support, feedback, and contribution that no individual developer can replicate alone.
For a niche technology like multi-axis printing, community isn’t optional. It’s a prerequisite for adoption. Without a community, every new builder has to solve every problem independently. With a community, solutions are shared, common failure modes are documented, and the accumulated knowledge of all builders is available to each new one. The community also provides social proof: seeing that others have successfully built and used the system lowers the perceived risk for potential adopters, directly addressing Rogers’ observability attribute.
Feedback loops and iterative improvement. Open-source hardware development is inherently iterative. Users
DENNIS KLAPPE · UNIVERSITY OF TWENTE | 24

C H 0 2 2 . 3 T E C H N O LO GY A D O P T I O N , A C C E S S I B I L I T Y, A N D
C O M M U N I T Y | D E M O C R AT I S I N G M U LT I - A X I S 3 D P R I N T I N G

build the system, encounter problems, and report them.
The developer *xes the design, and the next builder
bene*ts from the improvement. This feedback loop is the
engine of OSHW development, but it only works if there are enough active users to generate feedback, and if there are mechanisms (issue trackers, forums, direct communication) for that feedback to reach the developer. Antoniou et al. [20] identi*ed e-ective processes as one of the three themes of OSHW success, covering the activities and practices that contribute to a project’s development. Version control, structured issue tracking, and clear contribution guidelines all help. But the most important factor is simply having active users. A project with *ve active builders who report problems and suggest improvements will develop faster than a project with *,y passive observers.
Peer-to-peer knowledge transfer and makerspaces. Knowledge transfer in maker communities happens through multiple channels: documentation (build guides, wikis), visual media (YouTube videos, photos of builds), real-time communication (Discord, forums), and in-person interaction (makerspaces, conferences). Each channel serves a di-erent purpose. Documentation provides the reference. Visual media provides the context. Real-time communication provides the troubleshooting support. And in-person interaction provides the tacit knowledge that’s diScult to transfer through any other medium. Makerspaces can be particularly relevant for complex hardware projects. Seeing a multi-axis printer in person, watching it operate, and talking to the person who built it conveys information that’s hard to match online. But makerspaces are geographically limited. Online communities, while lacking the tacit knowledge transfer of in-person interaction, provide global reach. A Discord server with 100 members across di-erent countries provides a support network that no single makerspace can.
Case studies in accessible 3D printing
The history of consumer 3D printing provides several examples of how niche technology became accessible. Five projects are examined in detail in Appendix A, each analysed against Rogers’ adoption framework. The key *ndings are summarised here.
RepRap proved that self-replicating, open-source hardware can catalyse an entire industry [10]. But RepRap itself never crossed into mainstream adoption. Its complexity, fragmented documentation, and inability to “try before you build” kept it con*ned to the innovator demographic. The commercial derivatives that followed addressed those barriers.
Marlin *rmware became the dominant FDM *rmware not through individual adoption, but through manufacturers embedding it in commercial products [41]. Its GPLv3 licence ensures improvements 1ow back to the community. But Marlin’s con*guration model (editing C++ header *les, recompiling, and 1ashing) is a real accessibility barrier for users who need to make custom modi*cations, which is directly relevant to multi-axis printing.

Prusa Research is the clearest example of taking an open-source design from innovator to mainstream [42]. The key wasn’t the hardware but the packaging: documentation with assembly photos and troubleshooting, a reliable supply chain, and professional support. The company’s recent shi, from GPL to the more restrictive Open Community Licence (OCL) [43] illustrates the tension between openness and commercial sustainability when competitors can clone open-source designs [44]. Voron Design demonstrates that a purely community-driven project, with no commercial entity, can still reach broad adoption if the community infrastructure is strong enough [45]. Over 15,000 printers have been serialised as completed builds [46]. The Discord community e-ectively replaces the professional support that Prusa provides commercially, but this only works for an audience willing to engage with the community. Fig. 2.7 shows a Voron 2.4 mid-build.


FIG.2.7 A Voron 2.4 mid-build [47].
Klipper shows that architectural choices can be adoption choices [48]. By moving con*guration out of the compiled binary and into a text *le, and by pushing computation onto a host computer, the project removed two of the most signi*cant barriers Marlin still imposes: recompilation and *rmware-level debugging. The result is a thriving ecosystem of web-based front-ends like Mainsail and Fluidd, plus community-contributed macros, validating the approach of building browser-based tools rather than desktop applications. Klipper demonstrates that accessibility isn’t just about documentation or community; it’s also about the technical decisions made early in a project’s development. Fig. 2.8 compares the *ve projects against Rogers’ *ve adoption attributes. The pattern is clear: relative advantage is universally strong, but compatibility, complexity, trialability, and observability vary widely between projects, and the projects that achieved broad adoption (Prusa, Klipper) score consistently higher across the latter four.

### 2.4 DISCUSSION

Multi-axis FDM works. Andersons [18] and others have shown that, and the kinematic con*gurations, path-planning strategies, and calibration methods are all well understood. The problem isn’t solely technical.

DENNIS KLAPPE · UNIVERSITY OF TWENTE | 25

C H 0 2 2 . 4 D I S C U S S I O N | D E M O C R AT I S I N G M U LT I - A X I S 3 D P R I N T I N G


FIG.2.8 Rogers’ adoption attributes for the /ve case study projects.
The projects that took niche 3D printing into the mainstream didn’t get there on technical aspects only. They got there through documentation, community, and tools that made the thing easy to try. Bonvoisin et al. [34] show why open licences by themselves don’t cut it, and Rogers’ framework shows what’s still missing for multi-axis FDM: compatibility, trialability, complexity, and observability are all unresolved [19]. The gap isn’t in what multi-axis printing can do, it’s in who can do it.
The next chapter takes these *ndings and translates them into concrete requirements.
DENNIS KLAPPE · UNIVERSITY OF TWENTE | 26

C H A P T E R 0 3
03

# METHODOLOGY
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

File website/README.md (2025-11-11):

# Rep5x - Website

Official website for Rep5x open-source 5-axis 3D printer retrofit system.

## Quick start

```bash
npm install
npm run dev
```

## Tech stack

- **Astro** - Static site generator with component islands
- **Tailwind CSS** - Utility-first styling framework  
- **Cloudflare Pages** - Deployment platform with edge functions

## Folder structure

```
functions/          # Cloudflare Pages Functions  
public/             # Static assets
src/
  config/           # Site configuration
  content/          # Markdown content (blog posts, pages)
  layouts/          # Page templates and components
  pages/            # Website routes
  styles/           # CSS stylesheets
```

## Available scripts

- `npm run dev` - Start development server
- `npm run build` - Build for production
- `npm run preview` - Preview production build
- `npm run format` - Format code with Prettier

## Adding blog posts

This website is open source to enable community contributions. To add a blog post:

1. Create new markdown file in `src/content/blog/`
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

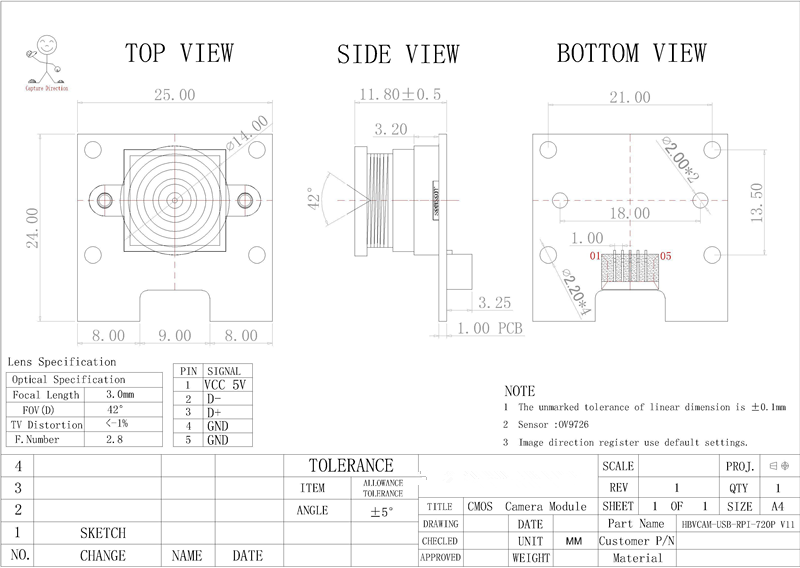
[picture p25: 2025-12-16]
tools/hardware/rep5x-camera/images/OV9726-camera-dimensions.png

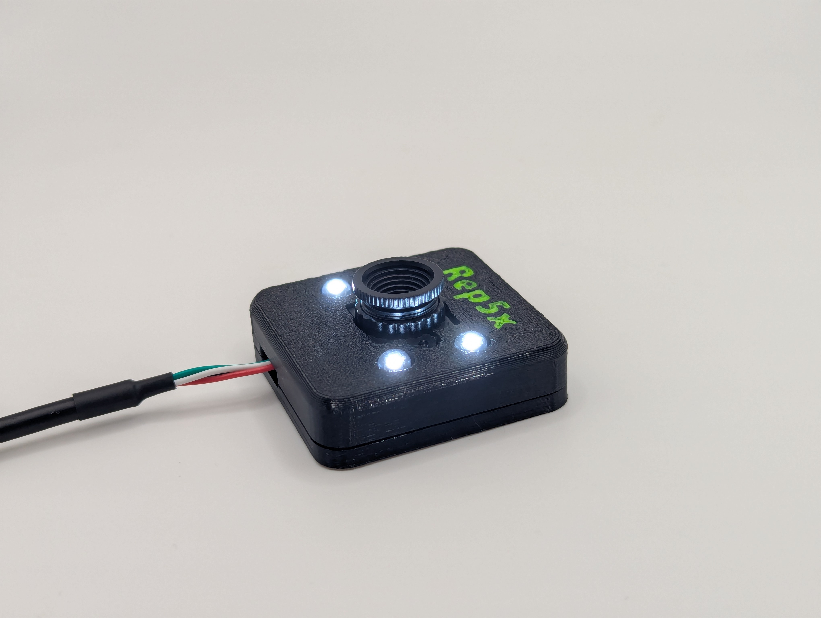
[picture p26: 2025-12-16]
tools/hardware/rep5x-camera/images/camera-finished-side-view.jpg

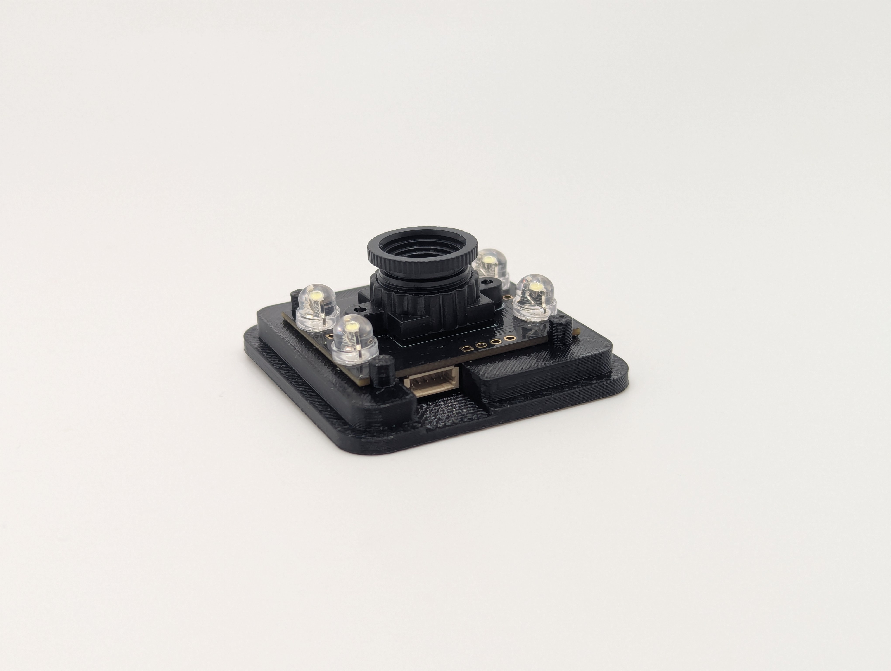
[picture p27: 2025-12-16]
tools/hardware/rep5x-camera/images/camera-mounted-on-base.jpg

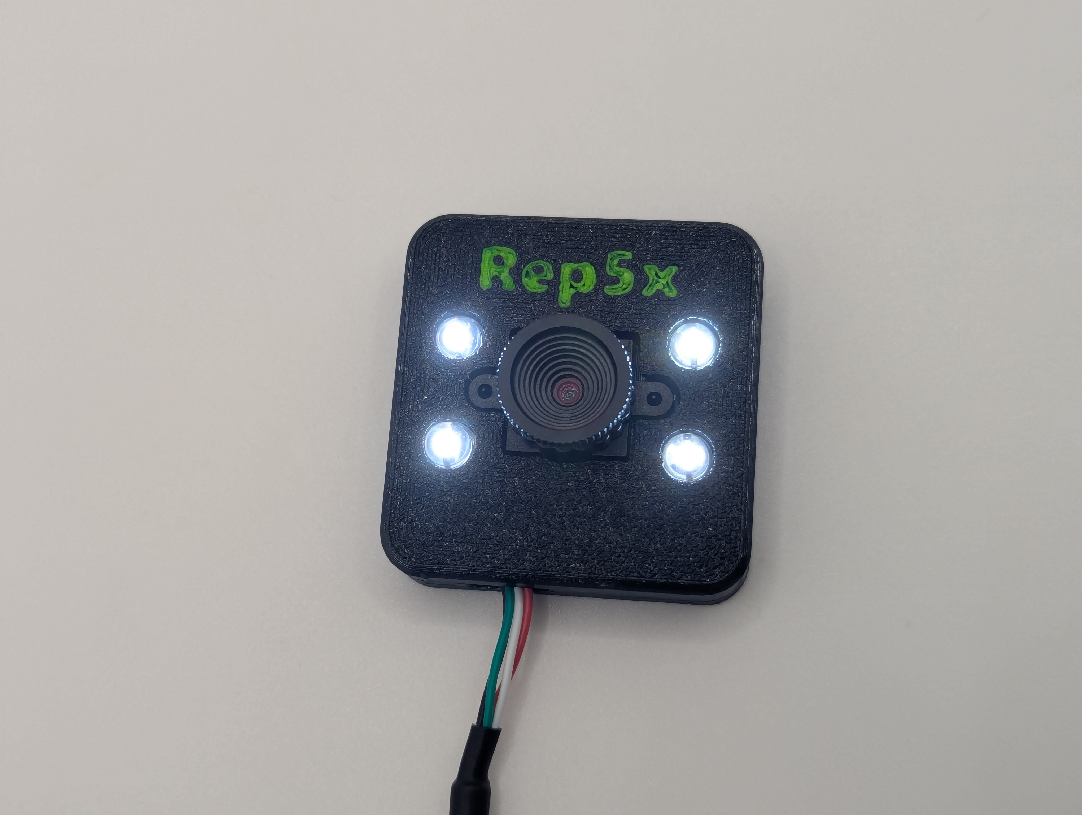
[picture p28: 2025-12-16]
tools/hardware/rep5x-camera/images/camera-finished-top-view.jpg

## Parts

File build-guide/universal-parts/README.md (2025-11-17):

# Rep5x - Shared components

Universal components and instructions that work across all supported Rep5x printer models.

## Overview

This folder contains everything you need to build a Rep5x 5-axis conversion that's common across all printer types. Printer-specific adaptations are in the [`../printer-specific/`](../printer-specific/) folder.

## Contents

### [`3d-printed-parts/`](3d-printed-parts/) - Printable components
Universal 3D printed components compatible with all printer models:
- **3MF files** - Ready-to-print models with optimized settings  
- **STEP files** - CAD files for modification and custom manufacturing
- **Assembly file** - Complete Fusion 360 assembly (FullAssem.f3z)

### Assembly documentation  
Complete step-by-step assembly guide:
- **[Assembly guide](../assembly-instructions-universal.md)** - Complete build instructions
- Phase-by-phase approach from planning to testing

### [`bill-of-materials/`](bill-of-materials/) - Component specifications
Universal component requirements:
- **[Shared BOM](bill-of-materials/bom-shared.md)** - Complete parts list with specifications
- Electronics, fasteners, and mechanical components
- Vendor suggestions and sourcing

### [`electronics/`](electronics/) - Electrical documentation
Control board and wiring information:
- **[Wiring diagrams](electronics/control-boards/)** - Complete wiring documentation
- Tested control board configurations

## Getting started

### Prerequisites
1. **Compatible 3D printer** - Check [`../printer-specific/`](../printer-specific/) for your model
2. **Basic tools** - 3D printer, hex keys, soldering iron, computer
3. **Electronics skills** - Basic wiring and firmware flashing
4. **Time commitment** - 24-34 hours total project time

### Build sequence  
1. **Plan** - Review all documentation and source components
2. **Print** - All universal 3D printed parts (~12-16 hours)
3. **Assemble** - Mechanical assembly following guide (~6-8 hours)
4. **Electronics** - Wiring and control board setup (~4-6 hours)
5. **Firmware** - Configuration and upload (~2-3 hours)
6. **Calibrate** - Setup and testing using web tool (~2-4 hours)

## Compatibility notes

### Universal design principles
- **Modular approach** - Printer-specific parts isolated to carriage mount
- **Standard interfaces** - Common fasteners and component sizes
- **Scalable electronics** - Works with various control board options
- **Open design** - All files available for modification

### Printer-specific requirements
While these components are universal, each printer requires:
- **Custom carriage mount** - Specific to X-carriage design
- **Mounting adaptations** - Frame attachment points and clearances
- **Wiring modifications** - Cable routing and lengths
- **Firmware adaptations** - Bed size and sensor configurations

## Version compatibility

Current version: **v1.1**

### Version tracking
- All components marked with compatible version numbers
- **v1.x** - Backward compatible updates (improvements, bug fixes)
- **v2.x** - Breaking changes requiring new parts or major modifications

### Upgrade path
- **v1.0 → v1.1** - Direct replacement, full compatibility
- **v1.x → v2.0** - Migration guide provided for major changes

## Support and resources

### Documentation hierarchy
1. **Start here** - [Assembly guide](../assembly-instructions-universal.md)
2. **Components** - [Shared BOM](bill-of-materials/bom-shared.md) for parts specifications
3. **Electronics** - [Wiring diagrams](electronics/control-boards/) for control board setup
4. **Printer-specific** - [`../printer-specific/`](../printer-specific/) for adaptations

---

**Ready to build?** Start with the [assembly guide](../assembly-instructions-universal.md) for complete step-by-step instructions. Join our [Discord community](https://discord.gg/GNdah82VBg) for support.

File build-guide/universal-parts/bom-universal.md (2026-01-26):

# Rep5x - Universal BOM

Universal components required for any Rep5x 5-axis printer conversion. These parts are compatible across all supported printer models.

## Universal 3D printed components

All files available in [`../3d-printed-parts/current/3mf/`](../3d-printed-parts/current/3mf/).

**Recommended material**: PETG for all components.

| Component | File | Description |
|---|---|---|
| C-driven-pulley | C-driven-pulley_v1.1.0.3mf | Drive pulley for C-axis |
| B-driven-pulley | b-driven-pulley_v1.1.0.3mf | Custom pulley for B-axis drive |
| B_arm | B_arm_v1.0.0.3mf | Rotational arm for B-axis |
| Slip ring holder | slip-ring-holder_v1.1.1.3mf | Mount for slip ring assembly |
| Spacer 3mm | spacer-3mm_v1.0.0.3mf | 3mm spacer component |
| Hotend spacer | hotend-spacer_v1.0.0.3mf | Spacer for hotend mounting |

## Universal COTS components

| Qty | Part Number | Description | Notes | Purchase links |
|-----|---|---|---|---|
| 2 | Nema17 stepper motor | Stepper motors for C and B axis | Standard 42mm body | [AliExpress](https://s.click.aliexpress.com/e/_c4c2iJMv)<br>[Amazon](https://amzn.to/4i9SpMc) |
| 2 | GT2 20T 5mm bore | Drive pulleys for C and B axis | 20 teeth, 5mm bore | [AliExpress](https://s.click.aliexpress.com/e/_c4c25zbJ)<br>[Amazon](https://amzn.to/3XxPq6t) |
| 1 | GT2 timing belt 6x188mm | Drive belt for C-axis | 6mm wide, 188mm length | [AliExpress](https://s.click.aliexpress.com/e/_c3iFUMNX)<br>[Amazon](https://amzn.to/3LBjJXs) |
| 1 | GT2 timing belt 6x158mm | Drive belt for B-axis | 6mm wide, 158mm length | [AliExpress](https://s.click.aliexpress.com/e/_c4EfUQFx)<br>[Amazon](https://amzn.to/3K1CsuB) |
| 2 | 608 2RS bearing DIN625 | Ball bearings for B-axis rotation | Standard skateboard bearings | [AliExpress](https://s.click.aliexpress.com/e/_c4TmSNYv)<br>[Amazon](https://amzn.to/4p7kIwW) |
| 2 | 61804 bearing | Thin section bearing for carriage mount | For C-axis rotation | [AliExpress](https://s.click.aliexpress.com/e/_c3f9UJ2d)<br>[Amazon](https://amzn.to/47YWRs9) |
| 1 | Microswitch | Endstop switch for B-axis | 2-pin micro limit switch | [AliExpress](https://s.click.aliexpress.com/e/_c3jaHbCv)<br>[Amazon](https://amzn.to/47Vp3w5) |
| 1 | Optical sensor | C-axis homing sensor | 3-pin optical endstop sensor | [AliExpress](https://s.click.aliexpress.com/e/_c2xizb7R)<br>[Amazon](https://amzn.to/3LGSqed) |
| 1 | Control board | 6+ stepper driver board | See tested control boards section| [AliExpress](https://s.click.aliexpress.com/e/_c4ahdz8D)<br>[Amazon](https://amzn.to/44cmTHi) |
| 6 | TMC2208 | Stepper drivers | UART mode, for all 6 axes | [AliExpress](https://s.click.aliexpress.com/e/_c3kOJ4tX)<br>[Amazon](https://amzn.to/444ykkm) |
| 1 | MST-005-12A slipring | Slipring assembly | 12 channels, 2A each, 5mm bore | [AliExpress](https://s.click.aliexpress.com/e/_c4bPjNQN)<br>[Amazon](https://amzn.to/3JRFemi) |
| 1 | Wire/cables | Connection wires | For slip ring and stepper connections | - |
| 1 | JST connectors (optional) | Removable connectors | For easy maintenance | [AliExpress](https://s.click.aliexpress.com/e/_c4TqCjzL)<br>[Amazon](https://amzn.to/4i4tx8f) |
| 1 | Cable organizers (optional) | Zip ties, cable clips, or spiral wrap | For clean wire routing | - |

## Universal fasteners

| Qty | Description | Purchase links |
|-----|---|---|
| 8 | DIN912 M3x6mm socket head cap bolt | [AliExpress](https://s.click.aliexpress.com/e/_c3Ylz0Rb)<br>[Amazon](https://amzn.to/4i7uBZa) |
| 8 | DIN912 M3x10mm socket head cap bolt | [AliExpress](https://s.click.aliexpress.com/e/_c3Y7jvop)<br>[Amazon](https://amzn.to/49SUXvN) |
| 2 | M3 heat-set insert for plastic | [AliExpress](https://s.click.aliexpress.com/e/_c3xF4D6N)<br>[Amazon](https://amzn.to/4pkGLjX) |

## Electronics requirements

### Control board requirements
- **Minimum stepper drivers**: 6 (X, Y, Z, E, A, B)
- **Processor**: 32-bit ARM recommended
- **Communication**: USB, UART support
- **Power**: 24V DC input capability

### Tested control boards
- **BTT Octopus V1.1** (STM32F446ZE) - 8 stepper drivers, proven working

### Stepper drivers
- **Required**: 6x TMC2208 (UART) or equivalent
- **Configuration**: X, Y, Z, Extruder, C-axis, B-axis
- **Benefits**: Unified driver type simplifies wiring and configuration

## Component specifications

### Slipring (MST-005-12A)
- **Channels**: 12 electrical channels
- **Current rating**: 2A per channel
- **Through-bore**: 5mm diameter
- **Purpose**: Allows continuous rotation

## Printer-specific components

The following components require printer-specific adaptation:

1. **Carriage mount** - Varies by printer X-carriage design
2. **Endstop positions** - May require relocation or addition

See printer-specific folders for adaptation requirements.

## Getting help

- **Assembly instructions**: See [assembly instructions](../../assembly-instructions-universal.md) for complete build instructions
- **Community support**: Join our [Discord community](https://discord.gg/GNdah82VBg) for help and discussions

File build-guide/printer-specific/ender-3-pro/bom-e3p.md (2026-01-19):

# Rep5x - Ender 3 Pro BOM

This BOM covers components specific to the Ender 3 Pro conversion. See the [universal BOM](../../universal-parts/bom-universal.md) for common components required across all printer models.

## Printer-specific 3D printed components

All files available in [`3d-printed-parts/3mf/`](3d-printed-parts/3mf/) and [`3d-printed-parts/step/`](3d-printed-parts/step/).

| Component | File | Description |
|---|---|---|
| Carriage mount | carriage-mount_v1.1.1.3mf | Mounts to Ender 3 Pro X carriage |
| Z endstop mount | z-endstop_v1.1.0.3mf | 3D printed mount for Z-axis endstop at Z max |

## Printer-specific COTS components

No additional COTS components required. The Ender 3 Pro already has a Bowden extruder setup with compatible components.

## Getting help

- **Assembly guide**: Follow main [assembly guide](../../assembly-instructions-universal.md)
- **Ender 3 Pro specifics**: See [README.md](README.md) for detailed differences
- **Discord**: Join our [Discord community](https://discord.gg/GNdah82VBg) for support

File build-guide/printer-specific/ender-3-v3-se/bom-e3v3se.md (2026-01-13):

# Rep5x - Ender 3 V3 SE BOM

This BOM covers components specific to the Ender 3 V3 SE conversion. See the [universal BOM](../../universal-parts/bom-universal.md) for common components required across all printer models.

## Printer-specific 3D printed components

All files available in [`3d-printed-parts/current/3mf/`](3d-printed-parts/current/3mf/) and [`3d-printed-parts/current/step/`](3d-printed-parts/current/step/).

| Component | File | Description |
|---|---|---|
| Carriage mount | carriage-mount_v1.1.1.3mf | Mounts to Ender 3 V3 SE X carriage |
| Y endstop mount | y-endstop_v1.1.0.3mf | 3D printed mount for Y-axis microswitch |
| Z endstop mount | z-endstop_v1.1.0.3mf | 3D printed mount for Z-axis microswitch on X gantry |

## Printer-specific COTS components

| Qty | Part Number | Description | Notes | Purchase links |
|-----|---|---|---|---|
| 2 | Microswitch | Endstop switches for Y and Z axes | 2-pin micro limit switch | [AliExpress](https://s.click.aliexpress.com/e/_c4MonxZx)<br>[Amazon](https://amzn.to/47VtY08) |
| 4 | M3 washer | Washers for yaw stepper mounting | 7mm OD | - |
| 1 | BTT Mini 12864 Display (optional) | LCD display | V3 SE stock screen not compatible - other compatible screens or headless operation also work | [AliExpress](https://s.click.aliexpress.com/e/_c36wGfe9)<br>[Amazon](https://amzn.to/3JDvGeD) |
| 1 | External Bowden extruder | Remote extruder assembly | Stock is direct drive | [AliExpress](https://s.click.aliexpress.com/e/_c38c2EU9)<br>[Amazon](https://amzn.to/49ikoqu) |
| 1 | Bowden-compatible hotend | Replacement hotend with PTFE coupling | Stock V3 SE hotend lacks Bowden retention | [AliExpress](https://s.click.aliexpress.com/e/_c2yOJW0z)<br>[Amazon](https://amzn.to/4o3crsJ) |
| 1 | PTFE Bowden tube | ~500mm PTFE tube | 4mm OD, 2mm ID | [AliExpress](https://s.click.aliexpress.com/e/_c3sghXBJ)<br>[Amazon](https://amzn.to/3X3DRns) |

**Alternative to hotend**: Modify stock hotend to retain Bowden tube.

## Firmware

Pre-configured Marlin 2.1.x firmware available in [`firmware/octopus-v1.1/`](firmware/octopus-v1.1/) folder:
- Configuration.h
- Configuration_adv.h
- firmware_rep5x_ender3v3se_octopus_v1.1.bin

See [firmware README](firmware/octopus-v1.1/README.md) for installation instructions.

## Getting help

- **Assembly guide**: Follow main [assembly guide](../../assembly-instructions-universal.md)
- **V3 SE specifics**: See [README.md](README.md) for detailed differences
- **Discord**: Join our [Discord community](https://discord.gg/pfTrx9uy8H) for support

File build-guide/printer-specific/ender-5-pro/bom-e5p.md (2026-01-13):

# Rep5x - Ender 5 Pro BOM

This BOM covers components specific to the Ender 5 Pro conversion. See the [universal BOM](../../universal-parts/bom-universal.md) for common components required across all printer models.

## Printer-specific 3D printed components

All files available in [`3d-printed-parts/current/3mf/`](3d-printed-parts/current/3mf/) and [`3d-printed-parts/current/step/`](3d-printed-parts/current/step/).

| Component | File | Description |
|---|---|---|
| Carriage mount | carriage-mount_v1.0.0.3mf | Mounts to Ender 5 Pro X carriage |

## Printer-specific COTS components

| Qty | Part Number | Description | Notes | Purchase links |
|-----|---|---|---|---|
| 1 | PTFE Bowden tube | ~700mm PTFE tube | 4mm OD, 2mm ID | [AliExpress](https://s.click.aliexpress.com/e/_c3sghXBJ)<br>[Amazon](https://amzn.to/3X3DRns) |

## Getting help

- **Assembly guide**: Follow main [assembly instructions](../../assembly-instructions-universal.md)
- **Discord**: Join our [Discord community](https://discord.gg/GNdah82VBg) for support

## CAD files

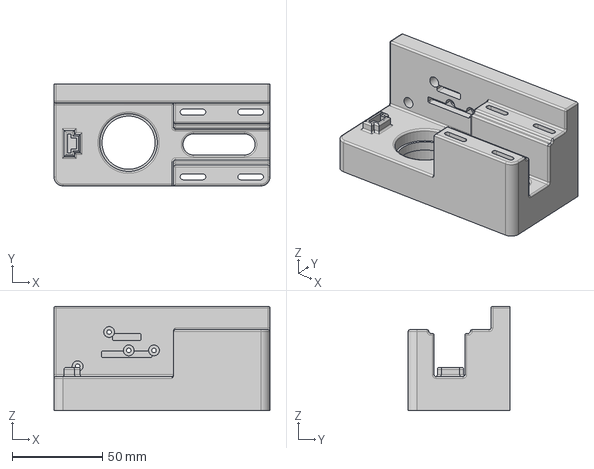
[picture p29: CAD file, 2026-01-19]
build-guide/printer-specific/ender-3-pro/3d-printed-parts/step/carriage-mount_v1.1.1.step
119.9 x 56.5 x 58.0 mm

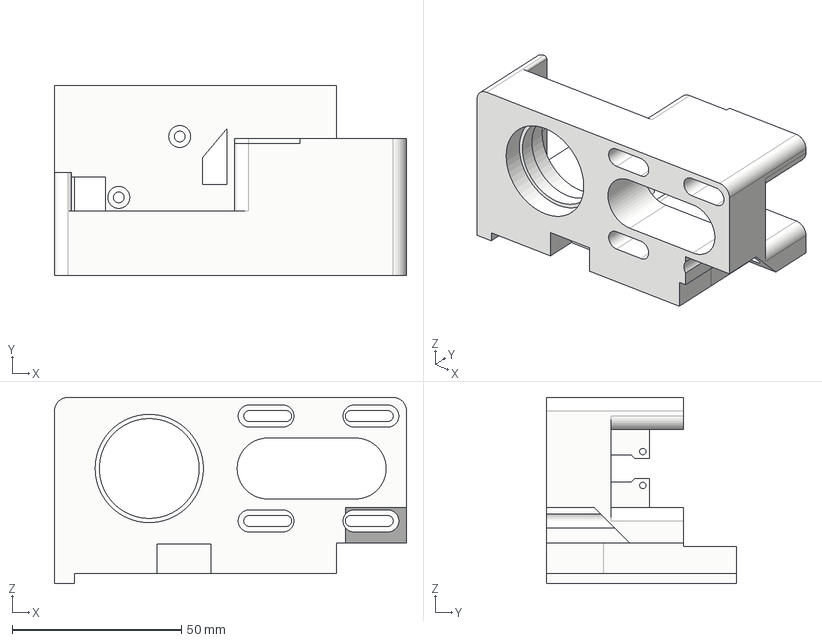
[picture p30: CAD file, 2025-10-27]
build-guide/printer-specific/ender-5-pro/3d-printed-parts/current/step/carriage-mount_v1.0.0.step
104.0 x 56.0 x 55.0 mm

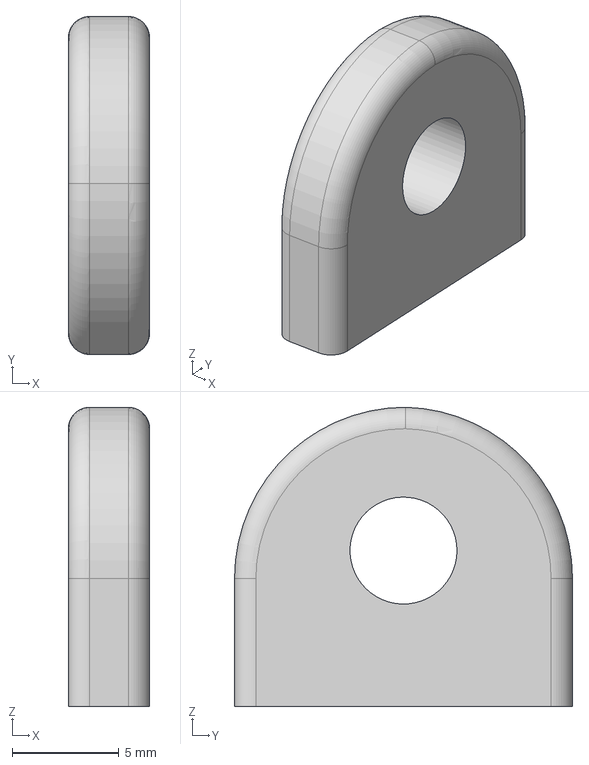
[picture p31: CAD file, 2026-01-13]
build-guide/universal-parts/3d-printed-parts/current/step/slip-ring-holder_v1.1.1.step
3.80 x 15.8 x 14.0 mm

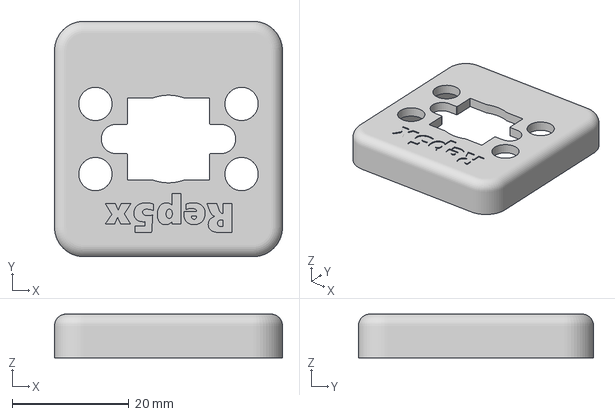
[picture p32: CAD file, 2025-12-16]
tools/hardware/rep5x-camera/models/current/3mf/camera-mount-top_v1.0.0.3mf
39.0 x 40.2 x 7.50 mm

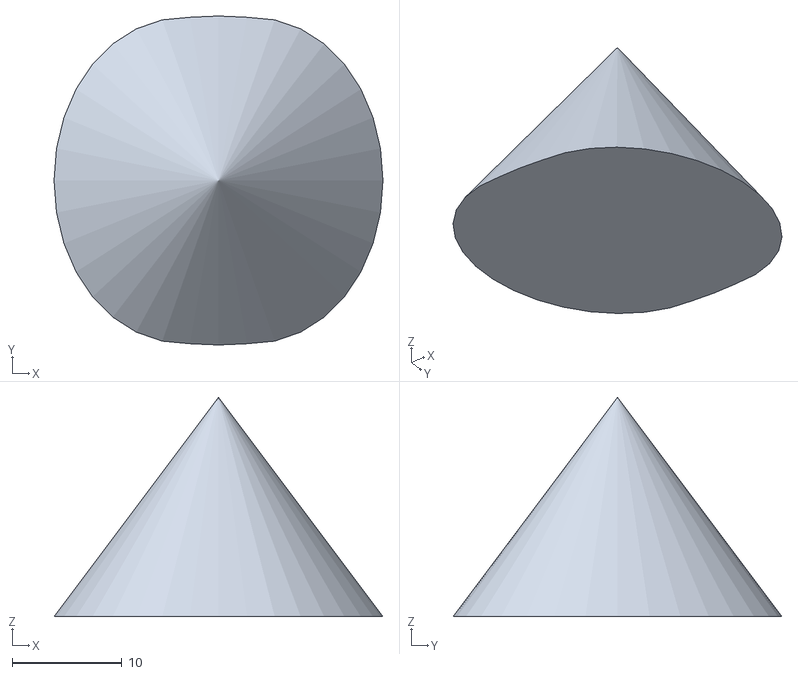
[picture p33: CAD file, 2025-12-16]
tools/lc-lb-measure/assets/calibration-cone.stl
30.0 x 30.0 x 20.0

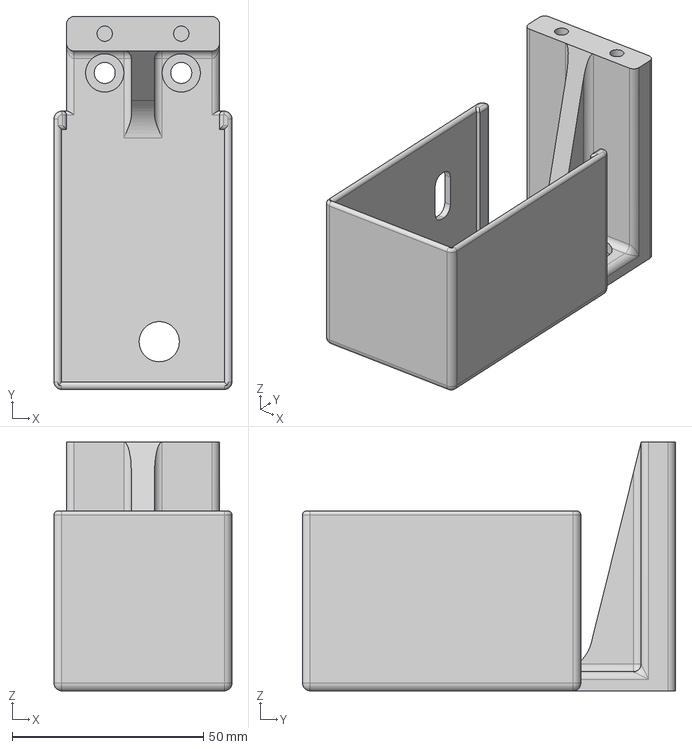
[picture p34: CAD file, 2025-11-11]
build-guide/printer-specific/ender-3-v3-se/3d-printed-parts/current/step/extruder-mount_v1.1.0.step
46.5 x 97.5 x 65.0 mm

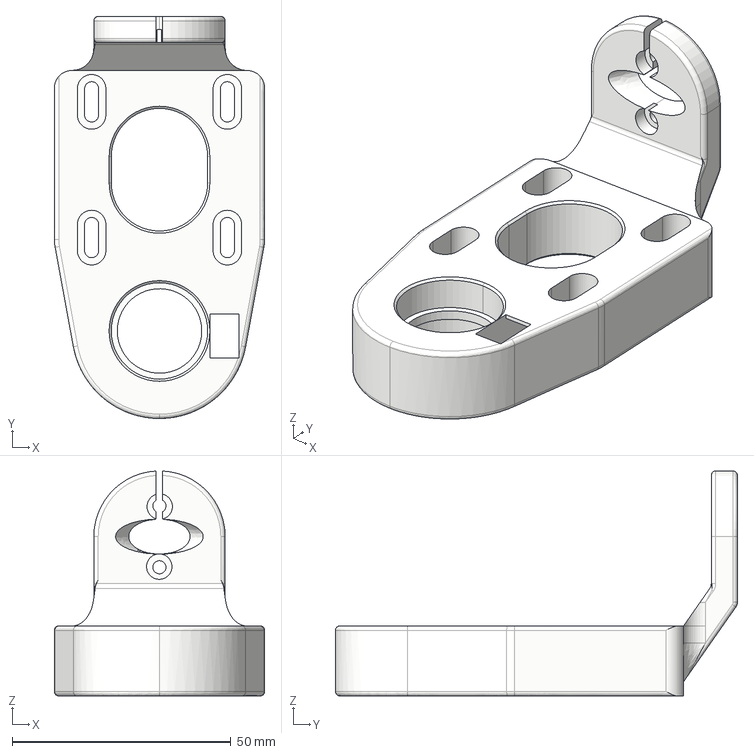
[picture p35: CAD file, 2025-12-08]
build-guide/universal-parts/3d-printed-parts/current/step/b-arm_v1.1.0.step
48.0 x 91.8 x 51.4 mm

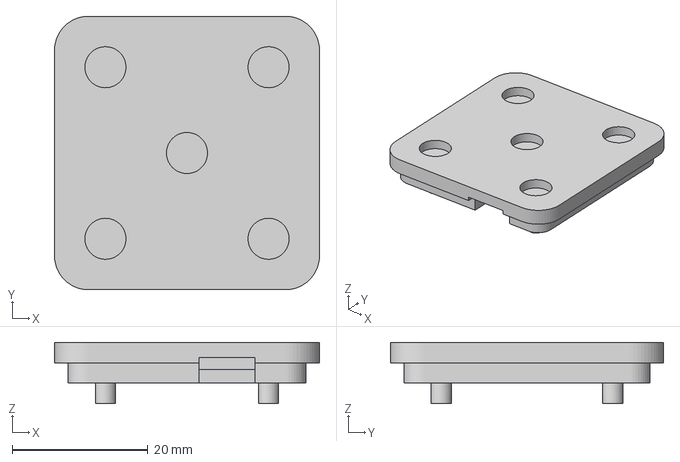
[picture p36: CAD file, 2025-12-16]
tools/hardware/rep5x-camera/models/current/3mf/camera-mount-bottom_v1.0.0.3mf
39.0 x 40.2 x 9.00 mm

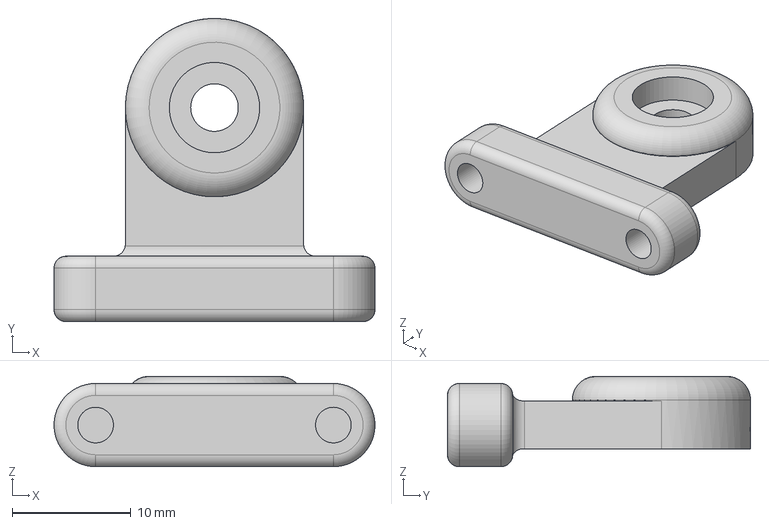
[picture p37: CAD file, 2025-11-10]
build-guide/printer-specific/ender-3-v3-se/3d-printed-parts/current/step/x-endstop_v1.1.0.step
27.0 x 25.5 x 7.60 mm

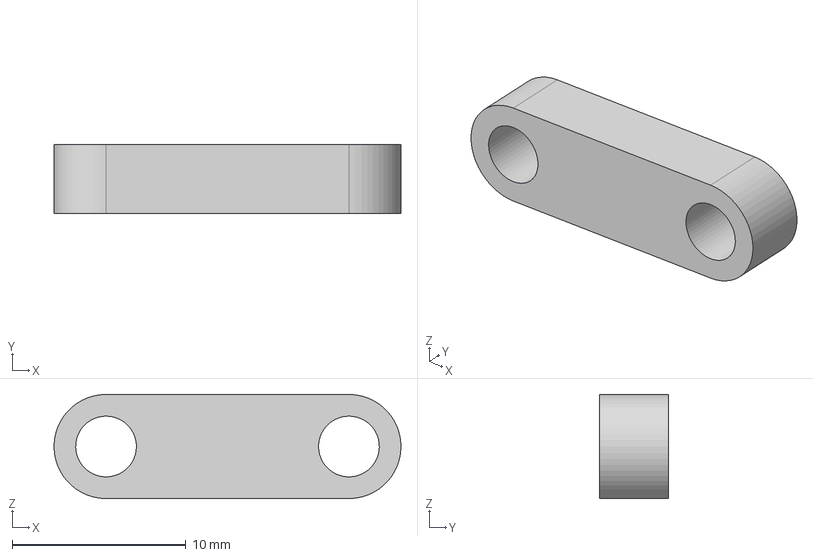
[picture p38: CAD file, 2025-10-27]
build-guide/universal-parts/3d-printed-parts/current/step/hotend-spacer_v1.0.0.step
20.0 x 4.00 x 6.00 mm

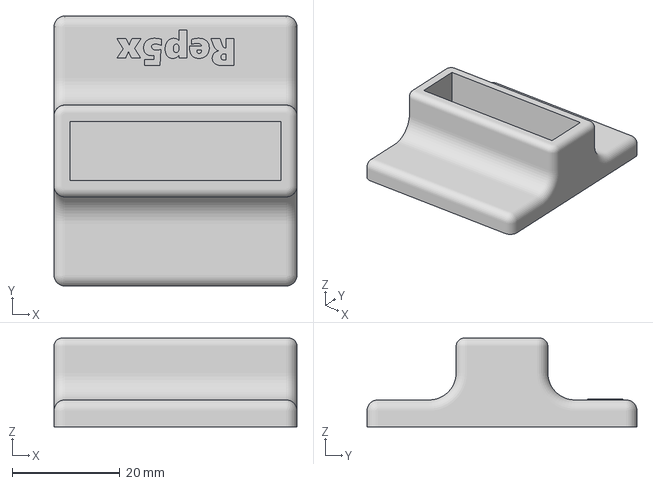
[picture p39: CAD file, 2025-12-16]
tools/hardware/rep5x-camera/models/current/3mf/camera-mount-z-axis_v1.0.0.3mf
45.0 x 50.0 x 16.5 mm

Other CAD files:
build-guide/printer-specific/ender-3-v3-se/3d-printed-parts/current/step/carriage-mount_v1.1.1.step
build-guide/printer-specific/ender-3-v3-se/3d-printed-parts/v1.1.1/step/carriage-mount_v1.1.1.step
build-guide/printer-specific/ender-3-pro/3d-printed-parts/3mf/carriage-mount_v1.1.1.3mf
build-guide/printer-specific/ender-3-v3-se/3d-printed-parts/current/3mf/carriage-mount_v1.1.1.3mf
build-guide/printer-specific/ender-3-v3-se/3d-printed-parts/current/3mf/extruder-mount_v1.1.0.3mf
build-guide/printer-specific/ender-3-v3-se/3d-printed-parts/current/3mf/x-endstop_v1.1.0.3mf
build-guide/printer-specific/ender-3-v3-se/3d-printed-parts/current/3mf/z-endstop_v1.1.0.3mf
build-guide/printer-specific/ender-3-v3-se/3d-printed-parts/current/step/z-endstop_v1.1.0.step
build-guide/printer-specific/ender-3-v3-se/3d-printed-parts/v1.1.0/3mf/carriage-mount_v1.1.0.3mf
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

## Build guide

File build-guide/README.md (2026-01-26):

# Rep5x - Build guide

Complete build documentation for converting 3D printers to 5-axis capability using the Rep5x open-source system.

## Quick start

1. **Check compatibility** - Verify your printer model in [`printer-specific/`](printer-specific/) (if not available, most printers need only minimal adaptations)
2. **Review requirements** - Universal components in [`universal-parts/`](universal-parts/)
3. **Follow assembly guide** - Complete instructions in [`assembly-instructions-universal.md`](assembly-instructions-universal.md)
4. **Join community** - Get support on [Discord](https://discord.gg/GNdah82VBg)

## Folder structure

### [`assembly-instructions-universal.md`](assembly-instructions-universal.md) - Main build instructions
Complete step-by-step assembly guide for converting any compatible printer to 5-axis capability.

### [`universal-parts/`](universal-parts/) - Universal build components
Contains components that work across all supported printer models:

- **[`3d-printed-parts/`](universal-parts/3d-printed-parts/)** - Universal STL, STEP, and Fusion 360 files
- **[`bill-of-materials/`](universal-parts/bill-of-materials/)** - Universal component list
- **[`electronics/`](universal-parts/electronics/)** - Control board and wiring guides

### [`printer-specific/`](printer-specific/) - Printer adaptations
Contains files specific to individual printer models:

- **[`ender-5-pro/`](printer-specific/ender-5-pro/)** - Ender 5 Pro specific files (Working)
- **[`ender-3-v3-se/`](printer-specific/ender-3-v3-se/)** - Ender 3 V3 SE files (In development)

## Supported printers

| Printer Model | Status | Carriage Mount | Notes |
|---|---|---|---|
| **Ender 5 Pro** | Working prototype | Available | Minimal notes |
| **Ender 3 V3 SE** | Working prototype | Available | Extensive build notes |
| **Generic adaptation** | Guidelines available | Custom required | See adaptation guide |

## Build overview

### Build requirements
- **Time**: ~24 hours (spread over several days)
- **Skills**: Basic 3D printing, electronics, and firmware knowledge (community happy to help if you lack some knowledge)
- **Tools**: 3D printer, soldering iron, hex keys, computer
- **Cost**: ~$150 in additional components

### Key components added
- **2x stepper motors** - C-axis (yaw) and B-axis (tilt) rotation
- **Control board upgrade** - 6+ stepper driver capability required  
- **Slip ring** - Continuous rotation without cable tangling
- **3D printed parts** - Custom mounting and drive components

## Getting started

### Step 1: Compatibility check
1. Find your printer in [`printer-specific/`](printer-specific/)
2. Review printer-specific requirements and limitations
3. Verify you have access to required tools and workspace

**Don't see your printer?** If your printer isn't listed, it can probably be adapted quite easily! Most printers only need a custom carriage mount bracket to work with Rep5x. If you don't have time to create the bracket yourself, feel free to ask in our Discord - many community members are happy to help. Adapting a bracket from one printer to fit another is usually straightforward work.

### Step 2: Order/source components
1. Review universal BOM in [`universal-parts/bill-of-materials/`](universal-parts/bill-of-materials/)
2. Add printer-specific components from your printer folder
3. Order/source electronics and hardware components (many can be sourced from old printers)

### Step 3: Print the parts
Print all required components using provided files

### Step 4: Begin build
1. Follow the complete guide in [`assembly-instructions-universal.md`](assembly-instructions-universal.md)
2. Assemble mechanical components following step-by-step instructions
3. Install and configure electronics and firmware

## Versioning system

Rep5x uses semantic versioning for hardware compatibility. See [VERSIONING.md](VERSIONING.md) for complete details.

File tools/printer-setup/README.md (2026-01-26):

# Rep5x - Printer setup

Calibrate Z height and C/B axis zero positions before kinematic calibration.

**Live tool:** https://tools.rep5x.com/printer-setup/

## Why is this needed?

Before measuring LC/LB parameters, your printer needs basic calibration:

- **Z-axis**: Z0 should be where the nozzle touches the bed
- **B-axis**: B0 should point the nozzle straight down
- **C-axis**: C360 should complete exactly one full rotation

## Features

- **Direction check**: Verify C and B motors rotate correctly
- **C-axis calibration**: Two-point measurement for rotation accuracy
- **B-axis calibration**: Two-point measurement for tilt accuracy
- **Z-axis calibration**: Paper test method for Z height
- **Auto-calculation**: Generates M206 and M92 corrections
- **Save to EEPROM**: Apply settings directly to printer

## Usage

1. Connect to your printer via USB
2. Check C and B axis directions (first time only)
3. Set C-axis reference positions (C0, C360)
4. Set B-axis reference positions (B0, B90)
5. Set Z0 using paper test method
6. Apply settings to printer

## Browser requirements

- **Chrome 89+** or **Microsoft Edge 89+** (Web Serial API)
- Firefox and Safari are not supported

## Next steps

After printer setup, continue to [LC/LB Measure](../lc-lb-measure/) to determine your kinematic parameters.

## File structure

```
printer-setup/
├── index.html
├── README.md
└── js/
    ├── app.js
    ├── connect.js
    ├── prepare.js
    ├── direction-check.js
    ├── c-axis.js
    ├── b-axis.js
    ├── z-axis.js
    └── apply.js
```

## Support

- **Discord**: [Join our community](https://discord.gg/GNdah82VBg)

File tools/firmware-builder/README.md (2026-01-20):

# Rep5x - Firmware builder

A web-based tool to configure and build custom Marlin firmware for your Rep5x 5-axis printer, with cloud compilation.

**Live tool:** https://tools.rep5x.com/firmware-builder/

## Features

- **Visual configuration wizard**: Step-by-step setup for all firmware settings
- **Cloud compilation**: Build firmware directly in your browser, no local toolchain needed
- **Save/load configurations**: Export your config as JSON, reload it later to make changes

## Quick start

1. Go to https://tools.rep5x.com/firmware-builder/
2. Follow the wizard to configure your printer settings
3. Click **"Build firmware.bin"** on the final step
4. Copy `firmware.bin` to an SD card and flash your printer

For detailed instructions, troubleshooting, and manual build options, see the [firmware guide](../../build-guide/universal-parts/firmware/).

## Support

- **Discord**: [Join our community](https://discord.gg/GNdah82VBg)

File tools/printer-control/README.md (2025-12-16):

# Rep5x - Printer control

A web-based control panel for your Rep5x 5-axis 3D printer, similar to Pronterface but running directly in your browser.

**Live tool:** https://tools.rep5x.com/printer-control/

## Features

- **5-axis jog controls**: Move X, Y, Z plus A (yaw) and B (pitch) axes
- **Configurable step sizes**: Linear (0.1, 1, 10, 100mm) and angular (1, 5, 15, 45, 90°)
- **Home controls**: Home individual axes or all at once
- **Emergency stop**: Quickly halt all movement
- **G-code console**: Send commands and view responses in real-time
- **Quick commands**: One-click access to common commands (M114, M503, M500, etc.)
- **Temperature controls**: Set hotend and bed temperatures
- **Auto-connect**: Automatically reconnects to previously used serial port
- **Clipboard copy**: Troubleshooting commands auto-copy responses to clipboard (formatted for Discord)

## Quick start

1. Go to https://tools.rep5x.com/printer-control/ (or open `index.html` locally in Chrome or Edge)
2. Click "Connect" and select your printer's serial port
3. Use the jog buttons to move the printer
4. Send G-code commands via the console

## Controls

### Jog buttons

- **X/Y pad**: Move in the horizontal plane
- **Z buttons**: Move up/down
- **A buttons**: Rotate around vertical axis (yaw)
- **B buttons**: Tilt nozzle (pitch)

### Keyboard shortcuts

| Key | Action |
|-----|---|
| Arrow keys | Jog X/Y |
| Page Up/Down | Jog Z |
| Home | Home all axes |
| Spacebar | Emergency stop |

### Quick commands

| Button | G-code | Description |
|---|---|---|
| Get position | M114 | Report current position (auto-copy) |
| Endstop status | M119 | Show endstop states (auto-copy) |
| Report settings | M503 | Show all firmware settings (auto-copy) |
| Firmware info | M115 | Show firmware version (auto-copy) |
| Save EEPROM | M500 | Save settings to EEPROM |
| Load EEPROM | M501 | Load settings from EEPROM |
| Reset defaults | M502 | Reset to factory defaults |
| Disable motors | M18 | Release stepper motors |
| Enable motors | M17 | Energise stepper motors |
| Absolute mode | G90 | Set absolute positioning |
| Relative mode | G91 | Set relative positioning |
| Get temps | M105 | Report temperatures (auto-copy) |

## Browser requirements

- **Chrome 89+** or **Microsoft Edge 89+** (Web Serial API support)
- Firefox and Safari are not supported

## File structure

```
printer-control/
├── index.html    # Main application
├── README.md     # This file
└── js/
    └── app.js    # Application logic
```

## Support

- **Discord**: [Join our community](https://discord.gg/GNdah82VBg)

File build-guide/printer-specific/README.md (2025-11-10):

# Rep5x - Printer-specific adaptations

Custom components and documentation for adapting Rep5x to specific 3D printer models.

## Overview

Each printer model requires specific adaptation components to interface with the universal Rep5x system. This folder contains printer-specific files that supplement the universal components in [`../universal-parts/`](../universal-parts/).

## Supported printer models

### [Ender 5 Pro](ender-5-pro/) - Working prototype
- **Status**: Fully functional
- **Components**: Custom carriage mount
- **Testing**: Proven design with working prototype
- **Community**: Active builders and support available

### [Ender 3 V3 SE](ender-3-v3-se/) - Working prototype  
- **Status**: Fully functional and documented
- **Components**: Carriage mount, X and Z endstop modifications
- **Testing**: Proven design with working prototype
- **Community**: Active builders and support available

## Printer-specific components

### What varies by printer model
While the core Rep5x components in [`universal-parts/`](../universal-parts/) are universal, these elements require printer-specific design:

#### Carriage mount (Required for all printers)
- **Purpose**: Interface between printer's X-carriage and Rep5x rotation assembly
- **Variations**: Mounting hole patterns, carriage dimensions, clearances
- **Files provided**: Both 3MF (printing) and STEP (modification) formats

#### Frame modifications (Varies by printer)
- **Endstop relocations**: Some printers need endstop position changes
- **Cable routing**: Printer-specific wire management solutions  

---

**Want to add support for your printer?** Start a discussion in our [Discord community](https://discord.gg/GNdah82VBg)!

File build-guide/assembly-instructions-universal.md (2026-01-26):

# Rep5x - Universal assembly instructions

Complete build instructions for converting any compatible 3D printer to 5-axis capability. Based on proven build process from working prototypes.

Throughout this guide you'll find affiliate links to components. Purchases through these links support the Rep5x project development and help keep the project open source.

## Before you start

**Important: Read through this entire document before beginning assembly.** This will help you understand the complete process, identify any missing components, and plan your build timeline effectively.

### Contributing improvements
If you discover easier methods, better techniques, or have suggestions for improvement during your build, please contribute back to the project:
- **Open a Pull Request** on GitHub with your proposed changes
- **Document your improvements** with photos and clear explanations  
- **Share your experience** in our [Discord community](https://discord.gg/GNdah82VBg)
- Help make Rep5x better for everyone!

## Prerequisites

### Tools required
- **3D printer** - For printing Rep5x components
- **Hex keys** - M2.5, M3 sizes (long hex key needed for C-axis stepper installation)
- **Wire strippers and connecting tools** - For wire connections (crimping tools if using JST, soldering iron if soldering)
- **Multimeter** - For electrical testing
- **Computer** - For firmware flashing and calibration

### Skills required
- **Basic 3D printing** - Print settings and quality control
- **Basic electronics** - Wiring and wire connections (soldering or crimping)
- **Firmware flashing** - Arduino IDE or VSCode with PlatformIO
- **Mechanical assembly** - Heat insert installation, bearing installation

### Time estimate
- **Electronics preparation**: 4-6 hours (board flashing, testing, slip ring prep)
- **Component preparation**: 2-3 hours (steps 5-9)
- **Mechanical assembly and installation**: 4-6 hours (steps 10-14)
- **Final testing and calibration**: 2-4 hours (step 15)
- **Total**: 12-19 hours over several days

## Part 1: Electronics preparation

### Step 1: Gather all materials

#### Verify you have all components from:
- **[Universal BOM](universal-parts/bom-universal.md)** - All shared components
- **[Printer-specific BOM](printer-specific/)** - Additional printer-specific components
- **3D printed parts** - All components printed and quality checked

### Step 2: Flash your control board

#### Download firmware configuration
Download the Marlin firmware configuration from your printer-specific folder:
**[Find your printer's firmware config](printer-specific/)**

#### Flash firmware
1. **Download Marlin 2.1.x** from official repository
2. **Replace configuration files** with Rep5x versions
3. **Compile and upload** to control board
4. **Verify upload successful** via serial connection

### Step 3: Remove old control board

1. **Power down printer** completely
2. **Disconnect all cables** from old control board
3. **Remove old board** from electronics enclosure

### Step 4: Install new control board and test basic functions

#### Install control board
1. **Place new board** next to your printer
2. **Set all jumpers correctly** according to the wiring diagram for your control board
3. **Install TMC2208 drivers** in all 6 positions (X, Y, Z, E, A, B)
4. **Connect all printer components** (steppers, end-stopsm
, heated bed, thermistors, hot-end etc.)
5. **Connect power supply** and verify 24V input

#### Test all components work correctly

Test each component with G-code commands:

**Motors (movement test):**
```gcode
G28        ; Home all axes
G1 X100    ; Test X motor
G1 Y100    ; Test Y motor  
G1 Z50     ; Test Z motor
G1 E10     ; Test extruder motor
G1 C10     ; Test C-axis motor (yaw rotation)
G1 B10     ; Test B-axis motor (tilt rotation)
```

**Heated bed:**
```gcode
M140 S60   ; Set bed temperature to 60°C
M105       ; Check temperatures
M140 S0    ; Turn off bed heater
```

**Hotend:**
```gcode
M104 S180  ; Set hotend to 180°C
M105       ; Check temperatures
M104 S0    ; Turn off hotend
```

**Thermistors:**
```gcode
M105       ; Read all temperatures - should show room temperature
```

**Endstops:**
```gcode
M119       ; Check all endstop status - should show current state
```

**Important**: All basic printer functions must work before proceeding.

## Part 2: Component preparation

### Step 5: Prepare slip ring with wire connections

#### Slip ring wiring requirements
The slip ring needs the following connections:
- **1x 4-pin connection** - For B-axis stepper motor
- **4x 2-pin connections** - For: hotend fan, hotend heater, hotend thermistor, B-axis endstop

#### Wire connection preparation
1. **Cut wires to appropriate lengths** for routing through slip ring (or keep full length for safety - prevents wires being too short, though cable management is harder)
2. **Connect wires** using your preferred method:
   - **JST connectors** (recommended) - Clean, removable connections
   - **Direct soldering** - Permanent but reliable, no prep needed for now
   - **Wire nuts or terminal blocks** - Alternative connection methods
3. **Test continuity** of all connections using a multimeter

**Note**: JST connectors are not required but preferred over permanent soldering for easier maintenance and troubleshooting.

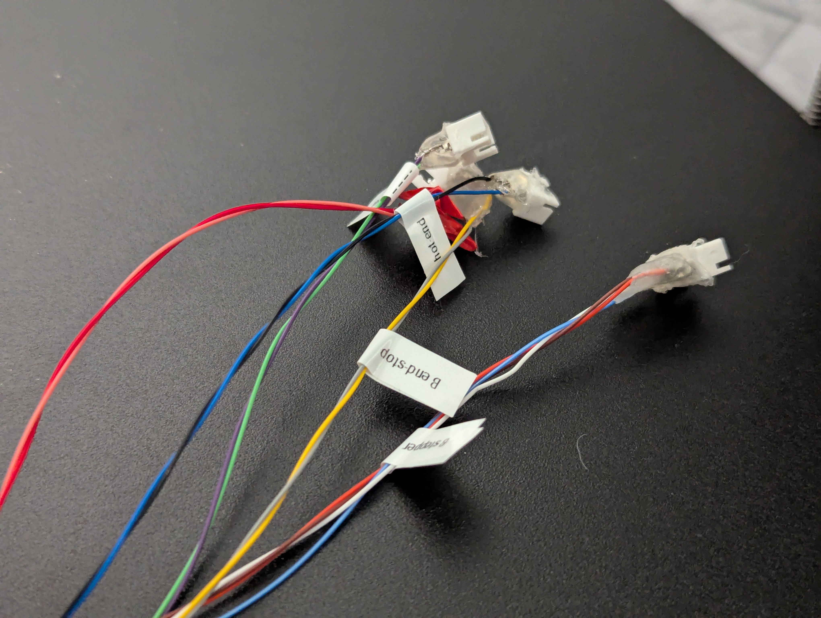
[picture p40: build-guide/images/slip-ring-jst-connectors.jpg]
Figure 1: Slip ring with JST connectors


*Figure 1: Slip ring prepared with JST connectors for easy connection and disconnection*

### Step 6: Prepare B-driven-pulley

#### Heat insert installation
1. **Install 2x M3 heat-set inserts** in B-driven-pulley
2. **Install M3x10 socket head bolt** in one insert
3. **Adjust bolt position** - should stick out slightly to trigger microswitch endstop
4. **Test fit** - bolt should protrude ~1-2mm for reliable endstop triggering

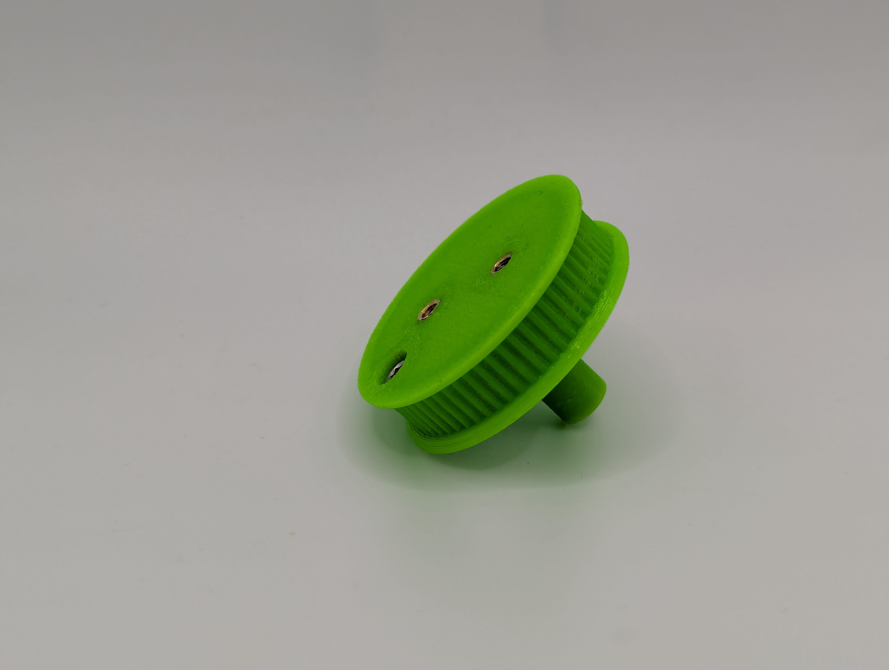
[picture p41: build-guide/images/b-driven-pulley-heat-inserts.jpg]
Figure 2: B-driven-pulley with heat inserts


*Figure 2: B-driven-pulley with heat-set inserts and endstop trigger screw installed*

### Step 7: Install bearings in B_arm

#### Bearing installation
1. **Install 2x 608 bearings** in B_arm bearing pockets
2. **Press fit carefully** - bearings should sit flush and rotate smoothly

### Step 8: Install and position microswitch in B_arm

#### Microswitch preparation
1. **Install microswitch** in B_arm mounting location
2. **Trim or remove metal actuator** needed for proper positioning
3. **Test position** - Install B-driven-pulley temporarily and check when screw clicks microswitch
4. **Find sweet spot** - Adjust for reliable triggering without interference
5. **Secure with hot glue** once optimal position found

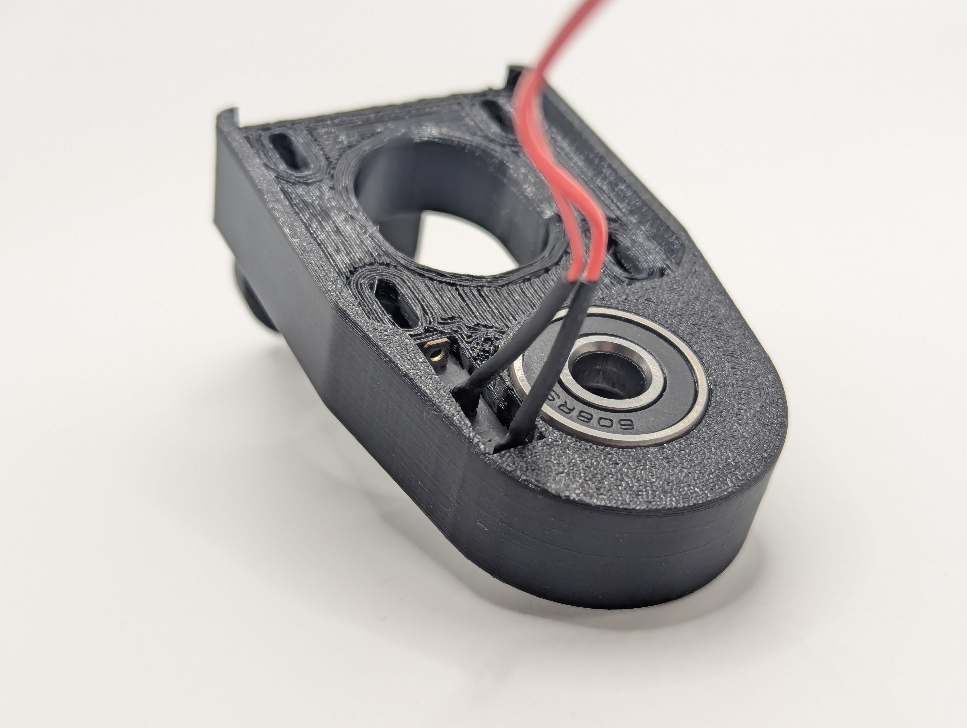
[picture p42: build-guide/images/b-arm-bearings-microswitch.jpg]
Figure 3: B_arm with bearings and microswitch


*Figure 3: B_arm assembly showing installed bearings and positioned microswitch*

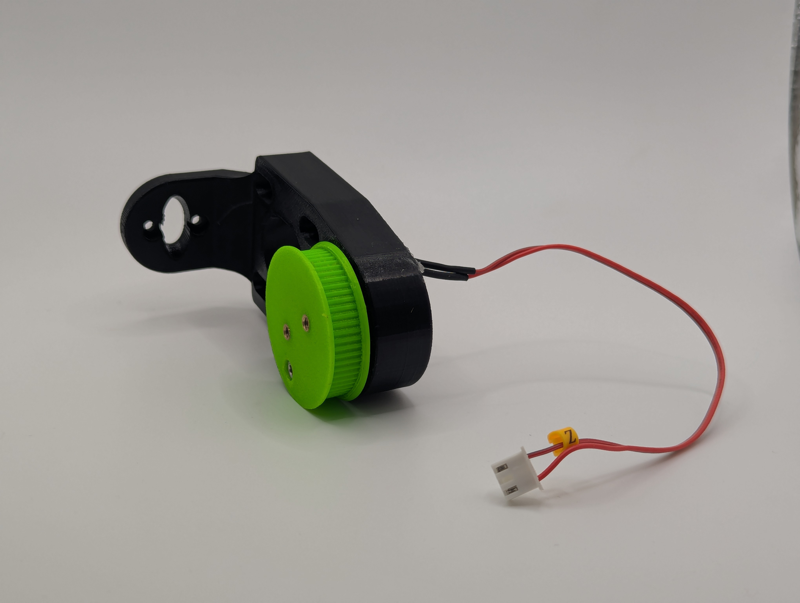
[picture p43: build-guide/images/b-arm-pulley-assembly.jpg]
Figure 4: B_arm with pulley assembly


*Figure 4: B_arm connected to B-driven-pulley, showing complete tilt mechanism*

### Step 9: Prepare carriage mount

#### Bearing installation 
1. **Install 2x 61804 bearings** in carriage mount
2. **Verify smooth rotation** and proper seating

**Note**: Do not install the C-driven-pulley yet - this must be done after attaching to the printer since the pulley blocks access to mounting screws on some printers like the Ender 3 V3 SE.

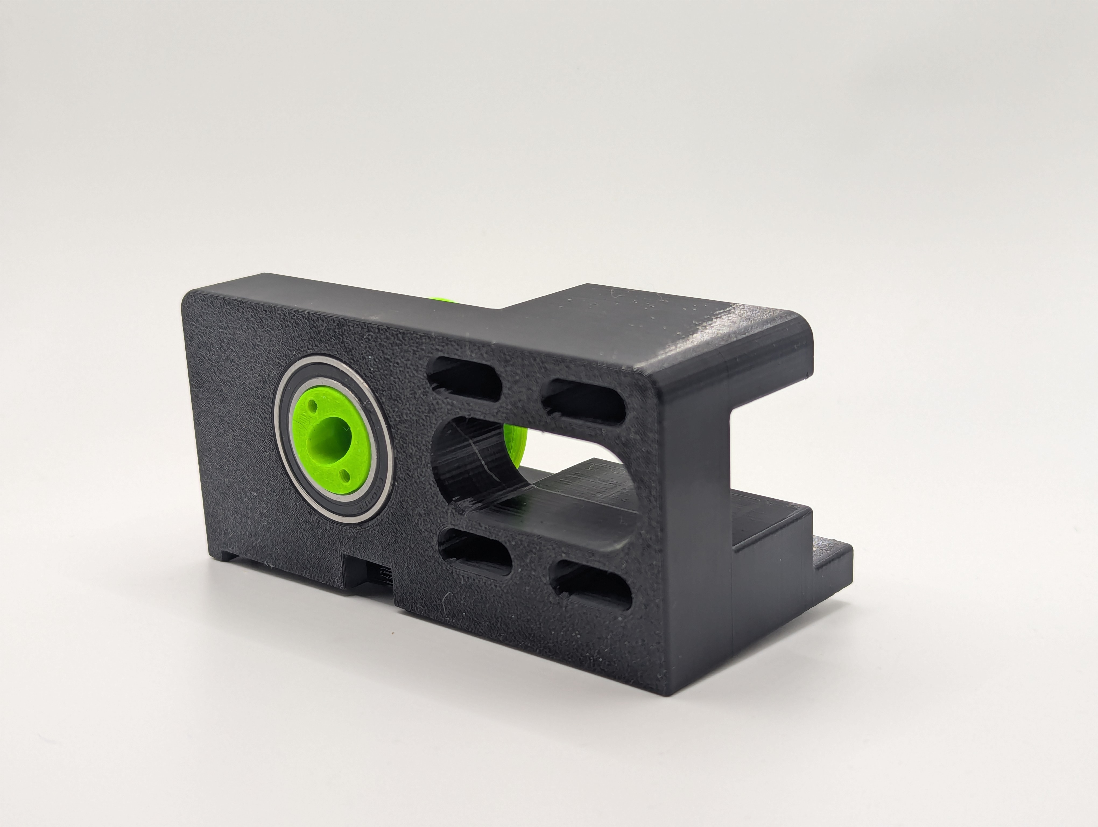
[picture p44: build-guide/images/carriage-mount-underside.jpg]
Figure 5: Carriage mount with bearings


*Figure 5: Carriage mount with 61804 bearings installed - ready for mounting to printer*

## Part 3: Installation on printer

### Step 10: Install carriage mount to X-axis

#### Carriage mount installation
1. **Remove original hotend assembly** from printer
2. **Attach carriage mount** to X-carriage using original mounting screws
3. **Verify clearance** with frame and motion systems

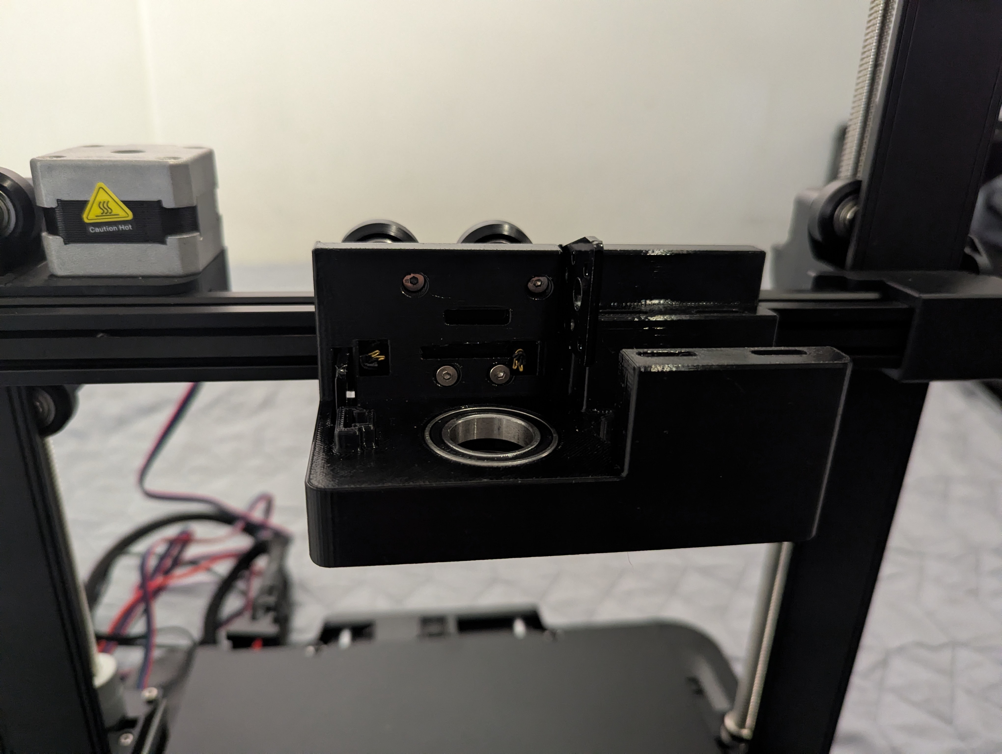
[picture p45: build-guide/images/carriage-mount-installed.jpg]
Figure 8: Carriage mount installed


*Figure 8: Carriage mount attached to printer's X-carriage*

### Step 11: Install C-axis drive system

#### C-axis pulley, stepper and drive installation
1. **Install C-driven-pulley** in carriage mount
2. **Add optical sensor** to carriage mount for C-axis position sensing
3. **Mount C-axis (yaw) stepper motor** to carriage mount using 4x M3x6mm bolts
4. **Use long hex key** to access stepper motor mounting bolts
5. **Install GT2 timing belt** connecting stepper motor to C-driven-pulley
6. **Tension belt properly** - should be snug but not over-tensioned
7. **Route slip ring wires** through the C-driven-pulley center hole
8. **Connect C-axis stepper** directly to control board (not through slip ring)

<div style="display: flex; gap: 20px; align-items: flex-start;">
  <div>
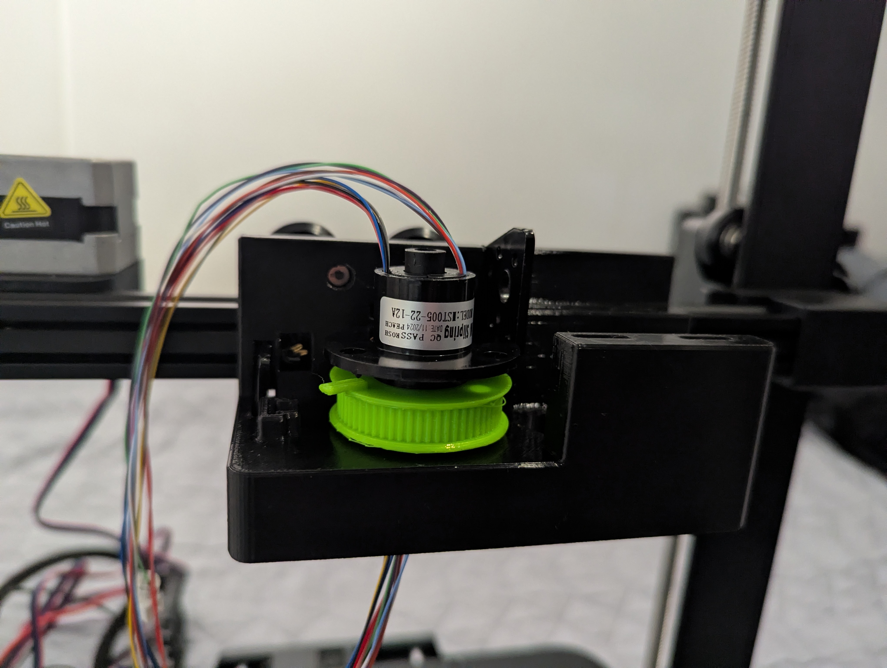
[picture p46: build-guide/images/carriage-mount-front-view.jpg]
Figure 8: C-axis pulley installation
    
    <p><em>Figure 8: C-driven-pulley installed in carriage mount</em></p>
  </div>
  <div>
    Figure 9: Complete C-axis installation
    <p><em>Figure 9: Complete C-axis installation with stepper motor and belt</em></p>
  </div>
</div>

### Step 12: Install B_arm and connect wiring

#### B_arm installation and wire routing
1. **Route all wires and Bowden tube** through B_arm center
2. **Attach B_arm to carriage mount** using 2x M3x10mm bolts
3. **Verify clearances** - Both C and B axes should move freely
4. **Test mechanical limits** - Check rotation range without collisions
5. **Secure wire routing** - No pinching or interference during motion

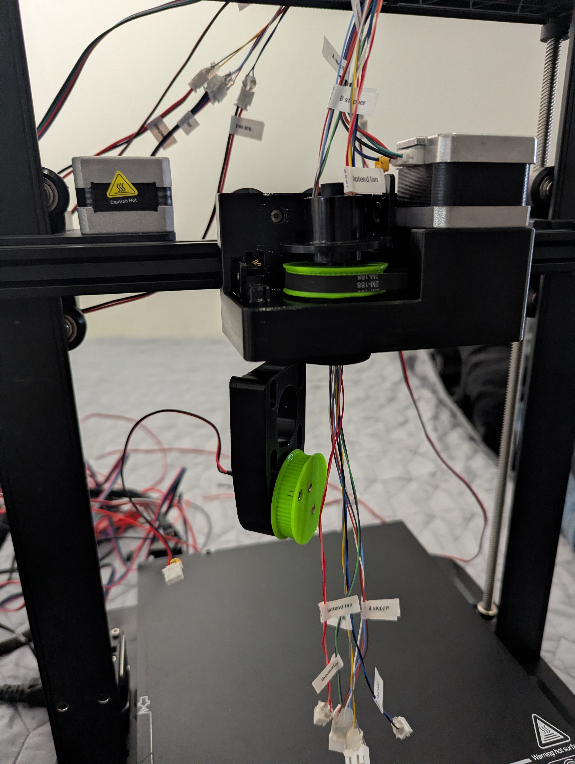
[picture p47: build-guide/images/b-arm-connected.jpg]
Figure 10: B_arm connected


*Figure 10: B_arm connected to carriage mount with proper wire routing*

### Step 13: Install B-axis drive system

#### B-axis drive system installation
1. **Install B-axis (tilt) stepper motor** to B_arm mounting points
2. **Install GT2 timing belt** connecting B-axis stepper to b-driven-pulley
3. **Tension belt properly** - should be snug but allow smooth rotation

### Step 14: Install hotend and final wiring

#### Hotend installation and complete wiring
1. **Attach hotend assembly** to B_arm mounting points
2. **Connect all hotend components** through slip ring connections:
   - Hotend heater (2-pin connection)
   - Hotend thermistor (2-pin connection)
   - Hotend cooling fan (2-pin connection)
3. **Connect B-axis stepper** through slip ring (4-pin connection)
4. **Connect B-axis endstop** through slip ring (2-pin connection)
5. **Check slip ring rotation** - should rotate freely without binding wires

#### Cable management
1. **Organize all wiring** for clean routing
2. **Secure loose cables** to prevent interference
3. **Test full motion range** with all cables connected

<div style="display: flex; gap: 20px; align-items: flex-start;">
  <div>
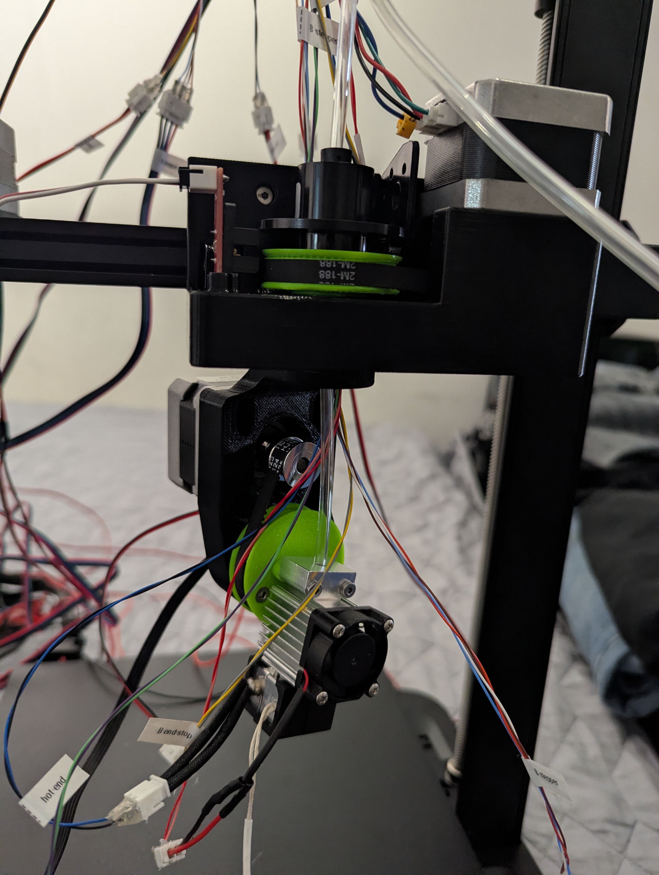
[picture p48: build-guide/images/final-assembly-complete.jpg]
Figure 11: Final assembly before cable management
    
    <p><em>Figure 11: Complete assembly with all components connected (before cable management)</em></p>
  </div>
  <div>
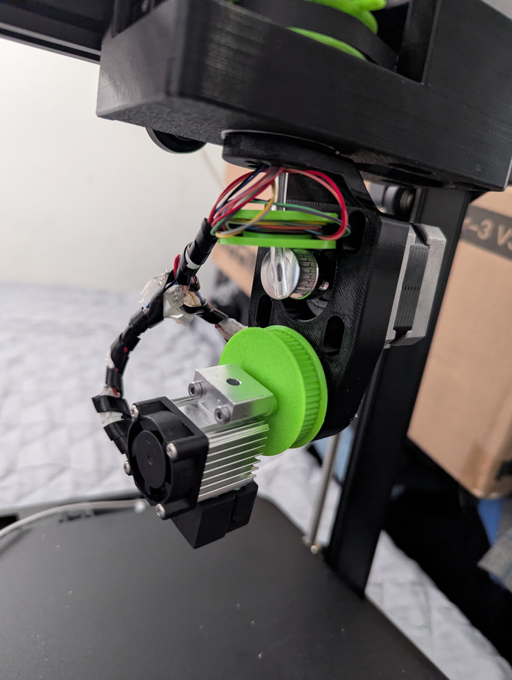
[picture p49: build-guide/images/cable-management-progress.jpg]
Figure 12: Cable management in progress
    
    <p><em>Figure 12: Same assembly with cable management in progress</em></p>
  </div>
</div>

<div>
  Figure 13: Completed Rep5x printer
  <p><em>Figure 13: Completed Rep5x 5-axis printer ready for calibration</em></p>
  <p><strong>Note:</strong> Improved cable management photos coming soon - this build was done with limited cable organizers.</p>
</div>

## Part 4: Testing and calibration

### Step 15: System verification and testing

#### System verification
1. **Power up system** and verify no error messages
2. **Test all 6 axes** with careful manual G-code commands:
   - X, Y, Z axes: `G1 X10 F1000` (move slowly, verify direction)
   - C-axis: `G1 C45 F1000` (rotate in 45° increments)
   - B-axis: `G1 B10 F1000` (tilt slowly, watch for collisions)
   - Extruder: `G1 E10 F100` (extrude 10mm slowly)
3. **Verify endstops** trigger properly with `M119` command
4. **Check thermal systems**:
   - Hotend heating: `M104 S200` (heat to 200°C)
   - Bed heating: `M140 S60` (heat to 60°C)
   - Verify temperature readings are stable

#### Extruder calibration

**Why calibrate the extruder:**
- Incorrect E-steps leads to over/under-extrusion, poor print quality

**How to calibrate E-steps:**

1. **Mark filament** - Make a mark 120mm above the extruder entrance
2. **Heat hotend** - `M104 S200` (or your printing temperature)
3. **Extrude 100mm** - Send command: `G1 E100 F100`
4. **Measure remaining distance** - Measure from extruder entrance to your mark
5. **Calculate actual extrusion** - Should be 20mm remaining (120mm - 100mm)
6. **Calculate new E-steps**:
   - If more than 20mm remains → extruding too little
   - If less than 20mm remains → extruding too much
   - Formula: `New E-steps = (Current E-steps × 100) / Actual distance extruded`
   - Example: Mark is at 25mm instead of 20mm → only 95mm extruded
   - New E-steps = (Current × 100) / 95
7. **Update firmware** - `M92 E[new value]` then `M500` to save
8. **Verify** - Repeat test to confirm accuracy

#### 5-axis kinematic calibration

1. **Use Rep5x calibration tool** at [calibrator.rep5x.com](https://calibrator.rep5x.com/)
2. **Follow cone or camera-based calibration** procedure:
   - Cone method: Print calibration cone and measure deviations
   - Camera method: Use computer vision to detect tool center point offset
3. **Update firmware** with calibrated kinematic parameters:
   - C-axis offset
   - B-axis offset
   - Tool center point (TCP) coordinates
4. **Test print** simple geometry to verify functionality

---

**Assembly complete!** Your Rep5x 5-axis conversion should now be ready for calibration and first prints. Join our [Discord community](https://discord.gg/GNdah82VBg) for support and to share your successful build!

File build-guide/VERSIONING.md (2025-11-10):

# Rep5x - Versioning

Version tracking for Rep5x hardware components using semantic versioning.

## Version format: `vMAJOR.MINOR.PATCH`

- **MAJOR** (`v1.0.0` → `v2.0.0`): Breaking changes, new parts required
- **MINOR** (`v1.0.0` → `v1.1.0`): Compatible improvements, optional upgrades
- **PATCH** (`v1.0.0` → `v1.0.1`): Minor fixes, direct replacements

## Current version: v1.1.0

### Compatibility:
- All v1.0.0 parts work with v1.1.0 parts
- Mix and match freely within v1.x versions
- Only print new parts if you want the improvements

## File naming:
3D printed parts include version: `B_arm_v1.1.0.3mf`

---

**Questions?** Ask in our [Discord community](https://discord.gg/GNdah82VBg)!

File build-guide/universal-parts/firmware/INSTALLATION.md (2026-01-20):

# Rep5x - Firmware installation guide

Step-by-step instructions for installing Marlin firmware on your Rep5x 5-axis printer.

## Method 1: firmware builder (recommended)

The **Firmware Builder** is the easiest way to get your Rep5x firmware:

**[tools.rep5x.com/firmware-builder](https://tools.rep5x.com/firmware-builder)**

### Step 1: configure your firmware

1. Open the Firmware Builder
2. Select your control board (e.g., BTT Octopus V1.1)
3. Enter your printer dimensions
4. Configure motor settings (drivers, steps per unit, directions)
5. Configure inverse kinematics parameters (LC, LB)

### Step 2: build and download

1. Review your configuration on the final step
2. Click **"Build firmware.bin"**
3. Wait for cloud compilation (usually 1-2 minutes)
4. Your `firmware.bin` and config file download automatically

### Step 3: flash to your board

1. Copy `firmware.bin` to a FAT32-formatted SD card (root directory)
2. Power off your printer
3. Insert the SD card into your control board
4. Power on - the firmware will flash automatically
5. The file will be renamed to `firmware.CUR` when complete
6. Run `M502` then `M500` to load default settings

### Step 4: iterate if needed

Found something wrong? (motor direction, homing issue, etc.)

1. Open the Firmware Builder again
2. Click **"Load"** and select your saved `rep5x-firmware-config-*.json` file
3. Make your changes (e.g., flip a motor direction)
4. Build and flash again

Your config file is automatically saved every time you build, so you can always pick up where you left off.

**That's it!** Continue to [verifying your installation](#verifying-your-installation) below.

---

## Method 2: manual build (advanced)

For users who need full control over their firmware or want to customise beyond what the tool offers.

### Prerequisites

- **Git** for cloning repositories
- **VSCode** with **PlatformIO extension** (recommended) or Arduino IDE
- **USB cable** for your control board
- Basic familiarity with command line

### Step 1: clone Rep5x-Marlin

Rep5x uses a custom Marlin fork with 5-axis support:

```bash
git clone https://github.com/dennisklappe/Rep5x-Marlin.git
cd Rep5x-Marlin
git checkout Marlin2ForPipetBot
```

### Step 2: copy configuration files

The base configuration for Rep5x with BTT Octopus V1.1 is included:

```bash
# Copy the Rep5x configuration
cp config/examples/Rep5x/Ender3V3SE_OctopusV1.1/Configuration.h Marlin/
cp config/examples/Rep5x/Ender3V3SE_OctopusV1.1/Configuration_adv.h Marlin/
```

Or use the reference configs from this folder as a starting point.

### Step 3: customise for your printer

Edit `Marlin/Configuration.h` to match your setup:

```cpp
// Bed dimensions
#define X_BED_SIZE 200
#define Y_BED_SIZE 200
#define Z_MAX_POS 170

// Homing directions (1 = MAX, -1 = MIN)
#define X_HOME_DIR 1
#define Y_HOME_DIR -1
#define Z_HOME_DIR 1

// Steps per unit (X, Y, Z, C, B, E)
#define DEFAULT_AXIS_STEPS_PER_UNIT { 80, 80, 400, 26.666, 26.68, 415 }

// Motor directions
#define INVERT_X_DIR false
#define INVERT_Y_DIR true
#define INVERT_Z_DIR false
#define INVERT_I_DIR true   // C-axis (yaw)
#define INVERT_J_DIR false  // B-axis (tilt)

// IK parameters
#define DEFAULT_ROTATIONAL_JOINT_OFFSET_Y 0.0    // LC
#define DEFAULT_ROTATIONAL_JOINT_OFFSET_Z 47.9   // LB
#define DEFAULT_TOOL_CENTERPOINT_CONTROL true    // Enable IK by default
```

### Step 4: build with PlatformIO

```bash
# Install PlatformIO CLI if not already installed
pip install platformio

# Build for BTT Octopus V1.1
pio run -e STM32F446ZE_btt
```

The compiled firmware will be at `.pio/build/STM32F446ZE_btt/firmware.bin`

### Step 5: flash to your board

1. Copy `firmware.bin` to SD card
2. Insert into control board and power on
3. Run `M502` then `M500` to load defaults

---

## Verifying your installation

After flashing, verify everything works using the [Printer Control](https://tools.rep5x.com/printer-control) tool.

### Check axis movement

**Important**: Test directions before homing! Move each axis manually first.

| Axis | Command | Expected movement |
|---|---|---|
| X | `G91` then `G0 X10` | Carriage moves RIGHT |
| Y | `G91` then `G0 Y10` | Bed moves FORWARD |
| Z | `G91` then `G0 Z10` | Printhead moves UP |
| C (yaw) | `G91` then `G0 I10` | Build plate rotates CLOCKWISE (from above) |
| B (tilt) | `G91` then `G0 J10` | Nozzle tilts LEFT |

**Wrong direction?** Either:
- Change `INVERT_X_DIR` (etc.) in Configuration.h and rebuild
- Or swap two wires in the stepper motor connector

### Check endstops

Send `M119` to check endstop status:

```
Reporting endstop status
x_max: open
y_min: open
z_max: open
i_min: open
j_min: open
```

Manually trigger each endstop and verify it changes to `TRIGGERED`.

**Always triggered or never triggered?** Change `X_MIN_ENDSTOP_HIT_STATE` between `HIGH` and `LOW` in Configuration.h.

### Test homing

Once directions and endstops are correct:

1. `G28 X Y` - Home X and Y (watch carefully, be ready to power off)
2. `G28 Z` - Home Z
3. `G28 I` - Home C-axis (yaw)
4. `G28 J` - Home B-axis (tilt)
5. `G28` - Home all

### Check heaters

```gcode
M104 S200    ; Heat hotend to 200°C
M140 S60     ; Heat bed to 60°C
M105         ; Check temperatures
```

Verify temperatures rise steadily and reach target.

---

## Next steps

1. **Calibrate C and B axes**: Use [Printer Setup](https://tools.rep5x.com/printer-setup) to set zero positions
2. **Calibrate IK parameters**: Use [IK Calibration](https://tools.rep5x.com/calibration) to measure LC and LB
3. **Test 5-axis motion**: Try simple tilted prints to verify kinematics

---

## Troubleshooting

### Build errors

#### Version mismatch
```
error: "Your Configuration.h file is for a different version of Marlin."
```
Make sure you're using the Rep5x-Marlin fork, not the main Marlin repository.

#### Missing endstop pins
```
error: "I_MAX_PIN, I_STOP_PIN, or I_SPI_SENSORLESS is required for I axis homing."
```
The C and B axis endstop pins need to be defined. For BTT Octopus V1.1:
```cpp
#define I_MIN_PIN PG13   // C-axis endstop
#define J_MIN_PIN PG14   // B-axis endstop
```

#### PID constant errors
```
error: "DEFAULT_Kp... are now (uppercase) DEFAULT_KP..."
```
Use uppercase: `DEFAULT_KP`, `DEFAULT_KI`, `DEFAULT_KD`

### Runtime issues

#### Axis moves wrong direction
Change `INVERT_X_DIR` (or corresponding axis) in Configuration.h, or swap two wires in the motor connector.

#### Endstop always triggered
Change `X_MIN_ENDSTOP_HIT_STATE` between `HIGH` and `LOW`.

#### Homing crashes into wrong end
Check `X_HOME_DIR` setting: `1` = homes to MAX, `-1` = homes to MIN.

#### IK not working (moves are wrong)
- Verify `DEFAULT_TOOL_CENTERPOINT_CONTROL true` is set
- Check LC and LB values match your toolhead geometry
- Run IK calibration with the calibration tool

---

## Support

- **Discord**: [discord.gg/GNdah82VBg](https://discord.gg/GNdah82VBg)

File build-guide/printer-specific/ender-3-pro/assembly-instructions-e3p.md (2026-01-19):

# Rep5x - Ender 3 Pro assembly instructions

Printer-specific assembly steps for the Ender 3 Pro. Follow the main [assembly instructions](../../assembly-instructions-universal.md) and complete these Ender 3 Pro-specific modifications.

## Z-axis endstop relocation

The Z endstop needs to be moved from Z min to Z max position. The cable will need to be extended or replaced to reach the top of the printer.

1. Remove the Z endstop from its original position at the bottom of the Z axis
2. Relocate the endstop to the top of the Z axis (Z max position)
3. Extend or replace the endstop cable to reach the new position
4. Adjust the trigger position so the nozzle homes at the correct Z height

## Continue assembly

Follow main [assembly instructions](../../assembly-instructions-universal.md) parts 1-4 to complete the Rep5x conversion.

## Getting help

- **Discord**: [Discord community](https://discord.gg/GNdah82VBg)

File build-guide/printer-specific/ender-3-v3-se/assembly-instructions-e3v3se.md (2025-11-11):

# Rep5x - Ender 3 V3 SE assembly instructions

Printer-specific assembly steps for the Ender 3 V3 SE. Follow the main [assembly instructions](../../assembly-instructions-universal.md) and complete these V3 SE-specific modifications.

## Z-axis endstop installation

Install microswitch on left side of X gantry using 3D printed Z endstop mount.

1. Remove the screw next to the Z-axis threaded rod on the left side of X gantry
2. Insert 3D printed Z endstop mount
3. Reinsert the original screw from step 1
4. Attach microswitch to mount

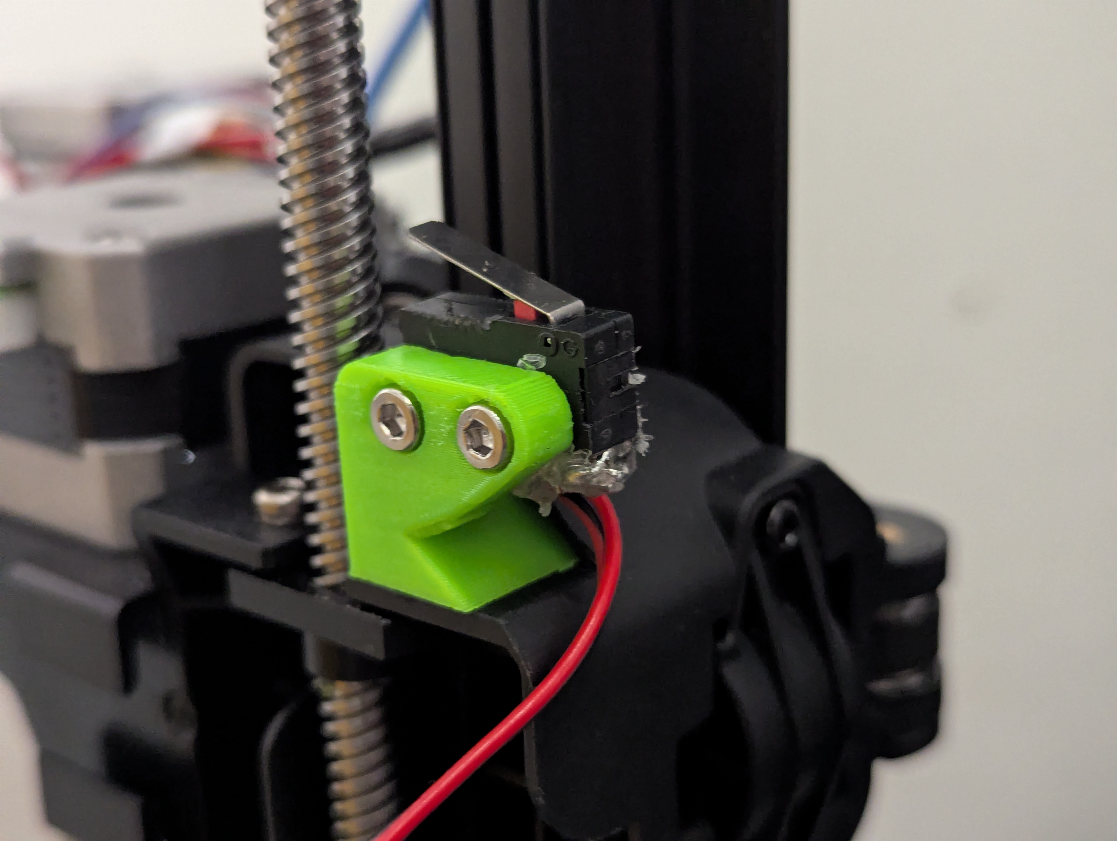
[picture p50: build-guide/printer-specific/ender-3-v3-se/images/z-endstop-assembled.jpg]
Figure 1: Z-axis endstop installed


*Figure 1: Z-axis endstop mounted on left side of X gantry*

## X-axis endstop installation

Install microswitch on right side of X gantry using 3D printed X endstop mount.

1. Remove the belt tensioning screw on the right side of X gantry
2. Insert 3D printed X endstop mount
3. Reinsert the belt tensioning screw
4. Attach microswitch to mount

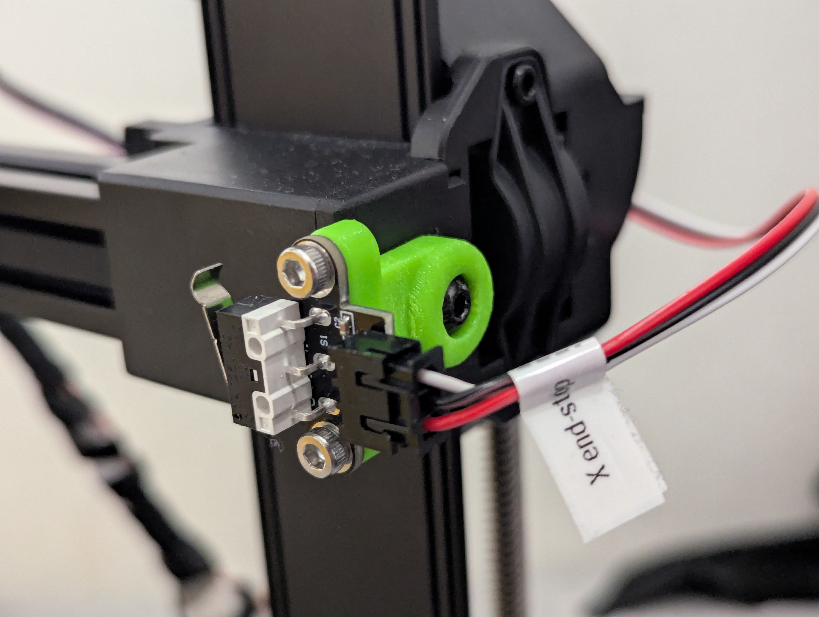
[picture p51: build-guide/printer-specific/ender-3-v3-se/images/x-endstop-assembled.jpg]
Figure 2: X-axis endstop installed


*Figure 2: X-axis endstop mounted on right side of X gantry*

## Extruder mount installation

Mount external Bowden extruder between spool holder and printer frame.

1. Remove original spool holder screws
2. Mount 3D printed extruder mount to printer frame using original spool holder screws
3. Attach external Bowden extruder to mount
4. Remount spool holder on top of extruder mount using M3x6mm screws (washers may be needed)
5. Route ~500mm PTFE Bowden tube from extruder to hotend

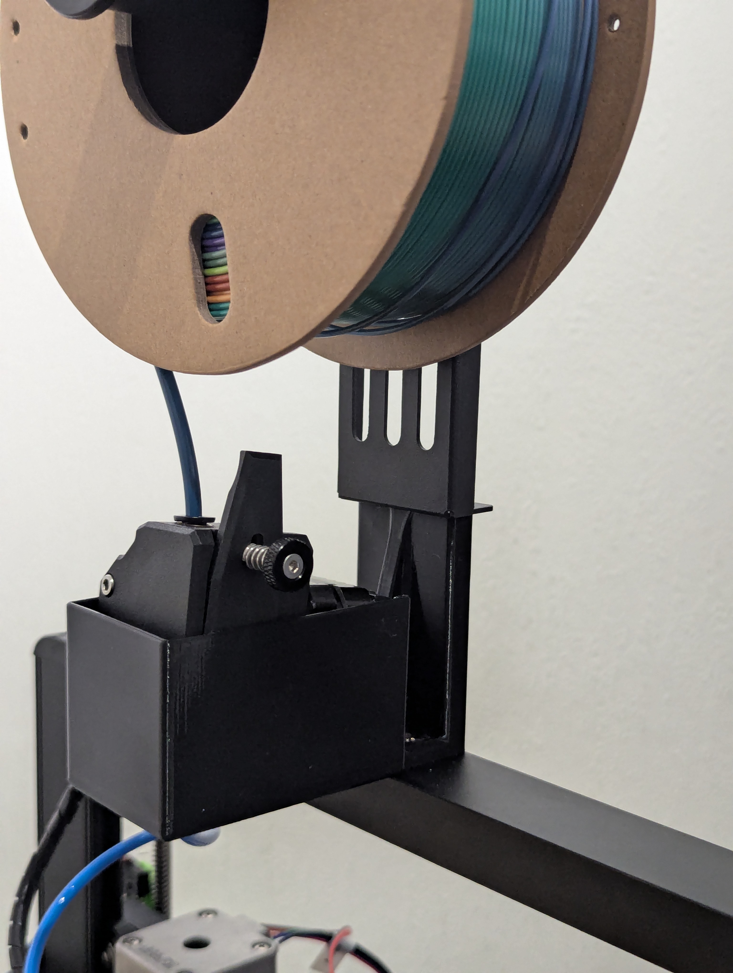
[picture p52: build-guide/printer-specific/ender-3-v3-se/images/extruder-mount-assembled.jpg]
Figure 3: Extruder mount installed


*Figure 3: External Bowden extruder mounted between spool holder and printer frame*

## Hotend modification

Stock hotend lacks Bowden tube retention. Either replace with Bowden-compatible hotend or modify stock hotend to retain PTFE tube.

## Display installation

Stock screen not compatible. Install BTT Mini 12864 display or run headless.

## Continue assembly

Follow main [assembly instructions](../../assembly-instructions-universal.md) parts 1-4 to complete the Rep5x conversion.

## Getting help

- **Discord**: [Discord community](https://discord.gg/GNdah82VBg)
- **Firmware**: Pre-configured Marlin in [`firmware/octopus-v1.1/`](firmware/octopus-v1.1/)

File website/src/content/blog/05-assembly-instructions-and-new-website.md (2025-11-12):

---
title: 'New website and assembly instructions'
description: 'Assembly instructions are now available and I am offering personal guidance to help builders succeed.'
date: 2025-11-12
image: '/images/blog/printer-complete.webp'
categories: ['community', 'hardware']
author:
  name: 'Dennis Klappe'
  designation: 'Masters Student'
  avatar: '/images/team/dennis-klappe.webp'
featured: true
---

I'm excited to share two updates for the Rep5x project: **assembly instructions are now available**, and we have a new website to make the project more accessible!

## Making 5-axis accessible to everyone

GitHub remains the heart of the development, all the files, documentation, and collaboration happen there. But after chatting with some people I realised that navigating GitHub can be intimidating if you're not familiar with it. That's why I created [Rep5x.com](https://rep5x.com) - a friendly front door to the project that won't scare away makers who might be put off by repository structures and markdown instructions.

The website offers:
- An introduction to what Rep5x is and can do
- The GitHub build guides with visual instructions
- Direct links to all the resources in our GitHub repository
- A less technical entry point for those new to open-source projects
- The same information, just presented in a more familiar web format

## Assembly instructions: ready for builders

<div class="rounded" style="height: 400px; overflow: hidden; display: flex; align-items: center; justify-content: center;">
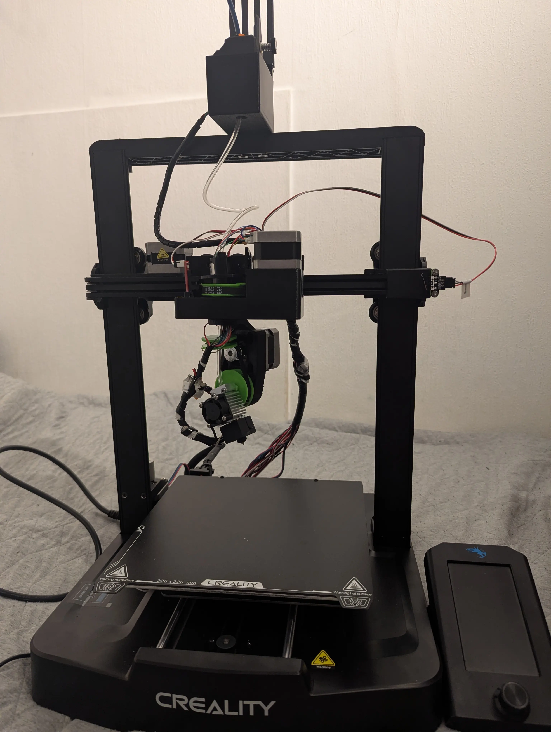
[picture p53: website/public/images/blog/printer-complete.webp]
Complete Rep5x 5-axis printer

</div>
<em>An assembled Rep5x printer ready for testing and better cable management</em>

After some refining of the build process, I've documented the main steps needed to convert a standard 3D printer into a 5-axis machine. The instructions are now available and tested on real builds.

The guide covers:
- **Electronics preparation** - Control board setup, firmware flashing, and wiring
- **Component assembly** - With photos of each step
- **Printer installation** - Mounting the 5-axis system to your existing printer

## Let's build together

**I'm looking for makers who want to build a 5-axis printer - I'd love to see your take on it and collaborate to improve the project together.** Your build experience will help identify gaps in documentation, pain points in the process, and areas that need refinement.

<div class="rounded" style="height: 350px; overflow: hidden; display: flex; align-items: center; justify-content: center;">
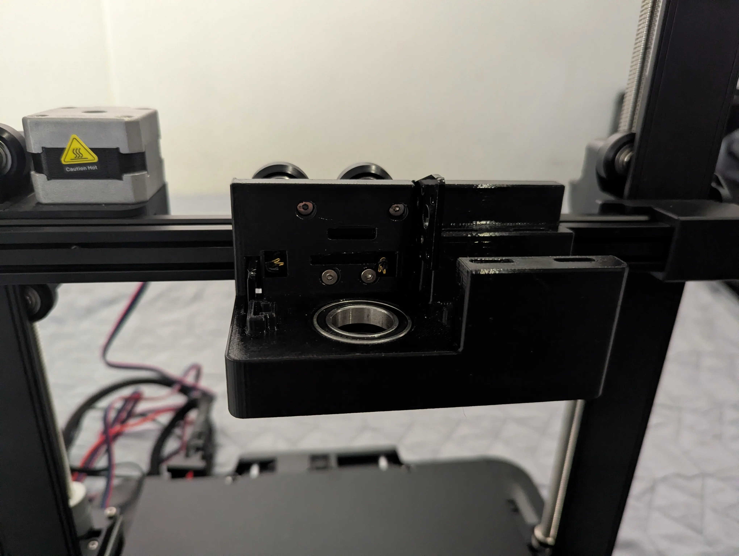
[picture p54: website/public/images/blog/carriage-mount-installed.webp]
Carriage mount installation

</div>
<em>The carriage mount is the foundation of the 5-axis system</em>

If you're interested in building a 5-axis printer, we can collaborate directly: I'll help with parts sourcing and printer compatibility questions, we'll troubleshoot challenges and document solutions, I'll assist with firmware configuration for your specific setup, together we'll work through calibration and first prints, and your feedback will help adapt the design and instructions.

This collaboration benefits everyone, your build helps improve Rep5x for the entire community while you get a working 5-axis printer.

## Ready to start?

The complete assembly instructions are available on our [build instructions page](/build-instructions/) and in our [GitHub repository](https://github.com/dennisklappe/Rep5x/blob/main/build-guide/assembly-instructions-universal.md), with universal instructions plus guides for specific printer models.

<div class="rounded" style="height: 800px; overflow: hidden; display: flex; align-items: center; justify-content: center;">
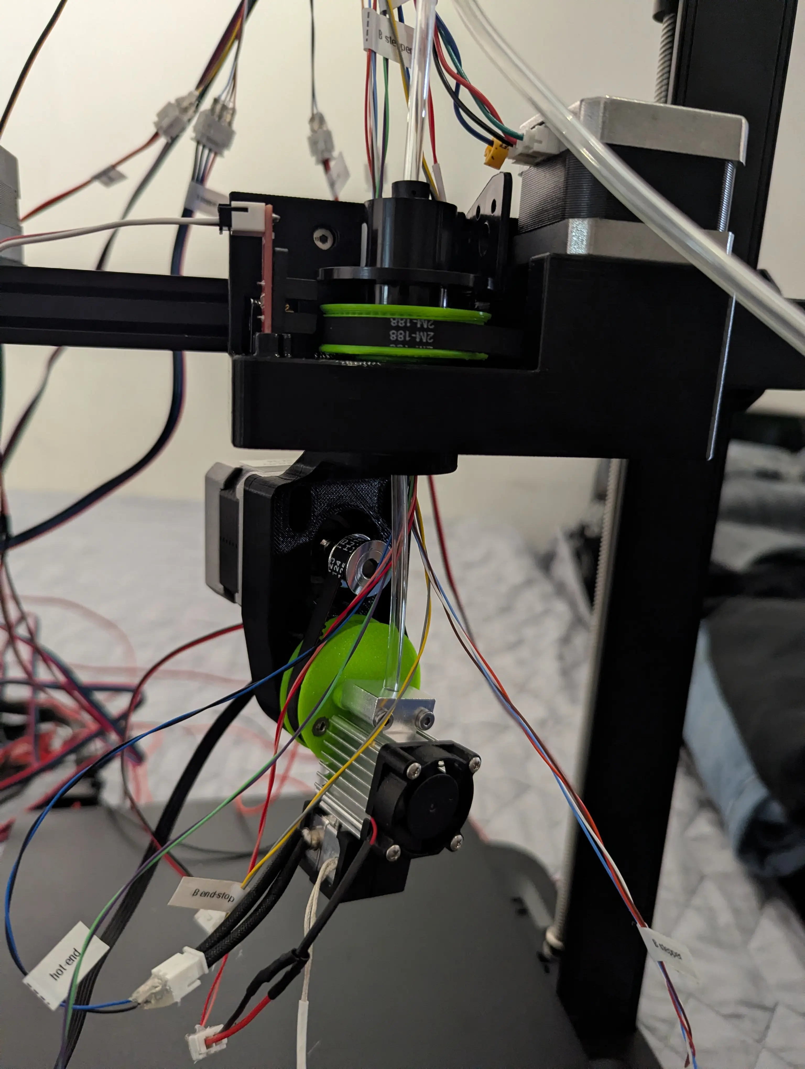
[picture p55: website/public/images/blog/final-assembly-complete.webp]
Final assembly before cable management

</div>
<em>Work in progress</em>

If you're interested in building a 5-axis printer or have questions, **[join our Discord](https://discord.gg/GNdah82VBg)** - the fastest way to reach me and other builders.

If you're an experienced maker with some 3D printing modification experience, I'd love to see your take on building a 5-axis printer. The website might make it easier to get started, and we can collaborate through the build process.

Let's expand what's possible with desktop 3D printing!

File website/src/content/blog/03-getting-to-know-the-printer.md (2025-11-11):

---
title: 'Getting to know the printer & simple calibration'
description: 'Initial testing and calibration work on the 5-axis printer system and discovering accuracy issues'
date: 2025-09-18
image: '/images/blog/offset-cone.webp'
categories: ['hardware', 'calibration']
author:
  name: 'Dennis Klappe'
  designation: 'Masters Student'
  avatar: '/images/team/dennis-klappe.webp'
---

To start off the project, I wanted to get to know the printer better and understand the basis of the build. The printer works quite well with simple scripts for basic shapes like tubes, but when you start printing complicated models with lots of movement, things get inaccurate.

## The problem

The printer has systematic errors in its positioning. When the print-head rotates, it doesn't end up exactly where the G-code tells it to go. Small mechanical imperfections, assembly tolerances, and maybe some flexibility in the 3D printed parts all add up. For complex geometries with lots of movement and rotations, the errors compound.

## My calibration approach

I needed a way to measure and correct these errors. Here's what I did:

I printed a cone and positioned the print-head where the tip should be according to the G-code. Then I manually moved it to where the tip actually was and noted the offset. I did this for different angles on both the A-axis (rotation around Z) and B-axis (tilt).

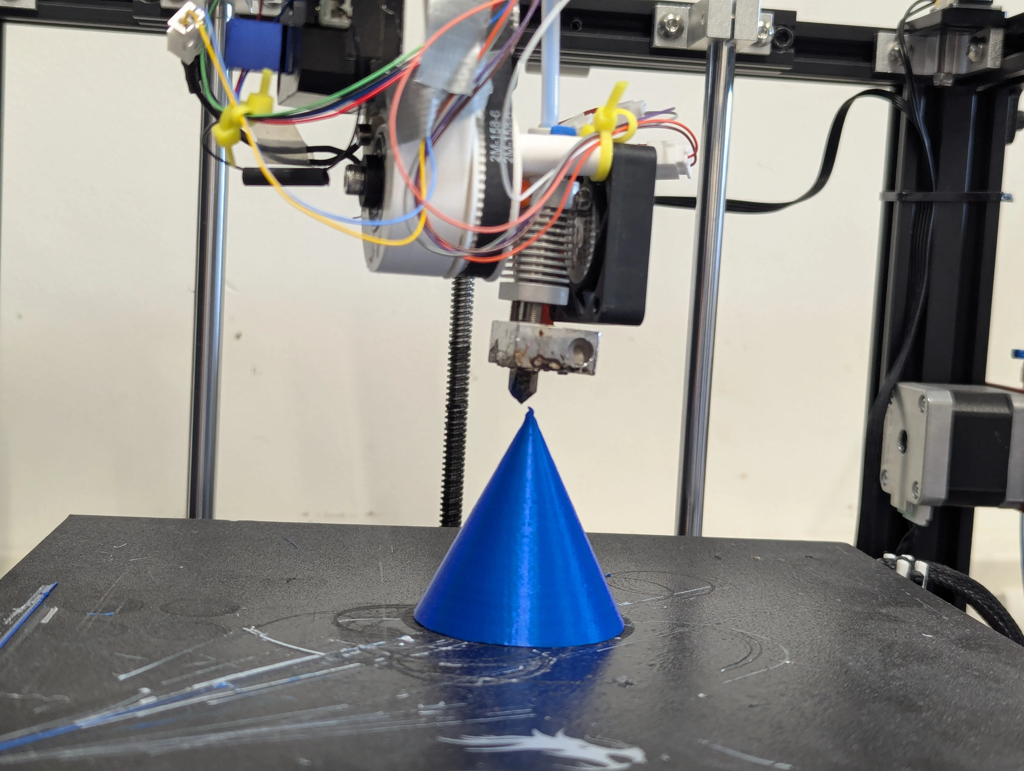
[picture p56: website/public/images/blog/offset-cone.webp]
Nozzle positioned at cone tip showing offset error


The A-axis showed cyclic errors, which makes sense for rotational movement. X corrections ranged from +0.3mm to -3.7mm, Y corrections from +2.2mm to -2.4mm. The pattern repeated every 360 degrees, as you'd expect.

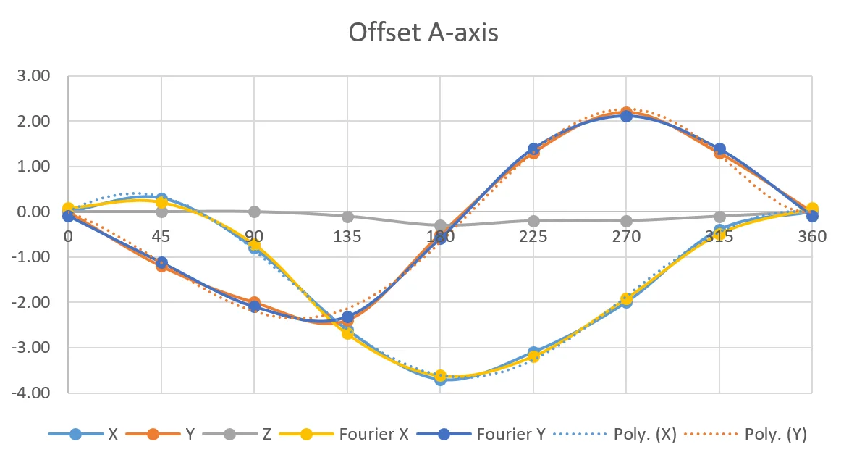
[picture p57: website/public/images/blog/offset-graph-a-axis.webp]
A-axis position errors showing cyclic pattern


<details>
<summary>View A-axis measurement data</summary>

| Angle | Error X | Error Y |
|---|---|---|
| 0° | 0 mm | 0 mm |
| 45° | +0.3 | -1.2 |
| 90° | -0.8 | -2.0 |
| 135°  | -2.6 | -2.4 |
| 180°  | -3.7 | -0.5 |
| 225°  | -3.1 | +1.3 |
| 270°  | -2.0 | +2.2 |
| 315°  | -0.4 | +1.3 |

</details>

The B-axis had different error patterns. Since it only tilts from 0 to 90 degrees, the errors were more linear.

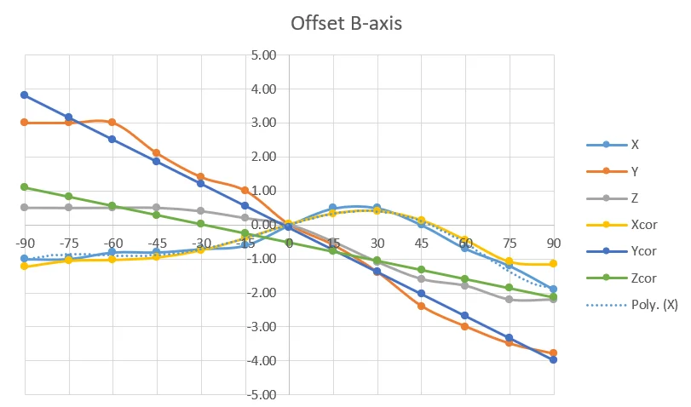
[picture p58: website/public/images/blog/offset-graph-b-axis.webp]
B-axis position errors showing different error patterns


<details>
<summary>View B-axis measurement data</summary>

| Angle | Error X | Error Y | Error Z |
|---|---|---|---|
| -90°  | -1.00 | +3.0 | +0.50 |
| -75°  | -0.99 | +3.0 | +0.50 |
| -60°  | -0.80 | +3.0 | +0.50 |
| -45°  | -0.80 | +2.1 | +0.50 |
| -30°  | -0.70 | +1.4 | +0.40 |
| -15°  | -0.60 | +1.0 | +0.19 |
| 0° | 0 mm | 0 mm | 0 mm |
| 15° | +0.50 | -0.6 | -0.51 |
| 30° | +0.50 | -1.4 | -1.10 |
| 45° | 0.00 | -2.4 | -1.60 |
| 60° | -0.70 | -3.0 | -1.80 |
| 75° | -1.21 | -3.5 | -2.20 |
| 90° | -1.90 | -3.8 | -2.20 |

</details>

## Finding the right correction method

First I tried fitting a polynomial function to the data that Excel automatically generates when creating a trendline on a scatter plot. Excel gave me a nice-looking curve, but it didn't work outside the calibration range. At 315 degrees, it wanted to correct by 24mm when the actual error was only 0.4mm. Polynomials are terrible for extrapolation.

The A-axis errors are cyclic and repeat every 360 degrees. Fourier series are well-suited for representing such periodic behaviour. Using just three harmonics, I got the average error down to 0.09mm across all calibration points.

For the B-axis, simpler fits worked fine. Linear for Y and Z, 6th-order polynomial for X (B stays within 0-90 degrees where the polynomial behaves).

## The Python script

I wrote a Python script that reads G-code, finds lines with A or B movements, applies the correction formulas, and outputs corrected G-code. When both axes move in the same line, it combines the corrections additively.

## What's your take?

I'm curious if anyone has other ideas for calibrating multi-axis printers. This cone-tip method worked, but it's tedious. Some alternatives I'm considering:
- Using a touch probe for automatic calibration
- Computer vision to track nozzle position
- Different test shapes that might reveal errors better

Please leave a comment if you have any input on this or [join the Discord](https://discord.gg/75Hy5dMwTJ) to have a chat!

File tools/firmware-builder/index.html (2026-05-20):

## Build your Rep5x Marlin firmware

Load Save

Step 1 of 6

1

2

3

4

5

6

Board Size Display Motors IK Build

### Select your control board

Rep5x requires a board with at least 6 stepper drivers (X, Y, Z, E, C, B).

#### BTT Octopus V1.1

8 stepper drivers, STM32F446, abundant I/O

Recommended

#### BTT Octopus Pro

Enhanced version with more features

Coming soon

#### BTT SKR 3

Compact board, requires expansion

Coming soon

#### Other board

Manual board configuration

Coming soon

Need a different board? Ask on Discord (https://discord.gg/GNdah82VBg) and I'll add support within a couple of days!

### Printer dimensions

Configure your build volume and motion limits.

Load preset - Quick-fill values for your printer

Build volume

Auto-adjust for Rep5x toolhead

X bed size (mm)

→ 200mm used (−20mm for Rep5x)

Y bed size (mm)

→ 200mm used (−20mm for Rep5x)

Z max height (mm)

→ 170mm used (−100mm for Rep5x)

Homing directions

X homes to

Depends on endstop location

Y homes to

Depends on endstop location

Z homes to

XY homing method

How do X and Y find home?

Z always uses its endstop.

Sensorless homing needs StallGuard-capable drivers, so X and Y drivers are set to TMC2209 and locked on the Motors step. Make sure the X/Y DIAG jumpers are installed on your board.

X stall sensitivity

Y stall sensitivity

Higher = more sensitive (TMC2209 range 0–255, default 8). Fine-tune later with M914.

Warning: Z MIN homing is risky. The Rep5x toolhead hangs below the X-gantry at varying heights depending on the yaw (C-axis) angle. Homing to Z MIN may crash the nozzle into the bed. Z MAX homing with an endstop at the top is strongly recommended.

### Select your display

Choose the LCD screen you'll be using with your printer.

#### BTT Mini 12864

Compact display with RGB backlight, encoder knob

Recommended

#### RepRap Full Graphic

Standard 128x64 LCD with SD card slot

#### CR-10 Stock Display

128x64 LCD with single 10-pin EXP connector (ST7920)

#### BTT TFT35

Touchscreen display with dual mode support

#### No display

USB/Serial control only (headless)

Backlight colour

Light

Enable a controllable LED (M355)

LED pin

Which board output the LED is wired to (a fan header).

Default brightness (0–255)

Off by default at power-up. Leave this section unchecked if your printer has no LED.

### Motor configuration

Configure stepper drivers, steps per unit, and motor directions.

#### Stepper drivers

Use same driver for all axes

Driver type

X driver

Y driver

Z driver

C driver

B driver

E driver

Dual Z steppers

Use a second Z stepper motor

The second Z motor runs in sync with Z and uses the same driver type. Pick its driver slot under Advanced ▸ Motor sockets below (default MOTOR7).

Independent Z endstops (auto-square the gantry when homing)

With independent endstops, wire the second Z endstop to the Z2-STOP header. Leave off to share a single Z endstop.

Steps per unit

X (steps/mm)

Y (steps/mm)

Z (steps/mm)

C (steps/deg)

B (steps/deg)

E (steps/mm)

Motor directions

Invert X Invert Y Invert Z Invert C (yaw) Invert B (tilt) Invert E

C-axis (yaw): Inverted by default for CNC convention where positive C = clockwise when viewed from above.

Endstop switches

Select NO (normally open) or NC (normally closed) based on your switch wiring.

X endstop

Y endstop

Z endstop

C endstop

B endstop

Advanced

Advanced: pins & motor sockets

##### Pin assignments

Each function is assigned to an MCU pin, prefilled with the Rep5x tutorial wiring. Change a pin if your board is wired differently — a warning shows if two functions share a pin.

##### Motor sockets

Which driver slot each axis is plugged into.

X motor

Y motor

Z motor

C motor (yaw)

B motor (tilt)

E motor

Z2 motor (dual Z)

Default assignment: X=MOTOR0, Y=MOTOR1, Z=MOTOR2_1, E=MOTOR3, C=MOTOR4, B=MOTOR5. This matches the standard Rep5x wiring for BTT Octopus.

### Inverse kinematics parameters

Configure the 5-axis inverse kinematics for your Rep5x toolhead.

Axis homing positions

C home position (degrees) - At endstop

Coordinate value assigned when C-axis hits home switch

B range (degrees) - Travel limit

B-axis travel limit (±value, e.g., 135 → -135° to +135°)

Toolhead geometry

LC (mm) - Y offset

Y-offset from yaw axis to nozzle

LB (mm) - Z offset

Z-offset from tilt axis to nozzle tip

LB is the distance from the B-axis pivot to the nozzle tip

Don't worry about exact values. LC and LB can be fine-tuned later using the IK Calibration tool after your printer is assembled. Start with the defaults and calibrate once everything is working.

Segments per second

Higher = smoother motion but more CPU load

### Review and build

Review your configuration and download the firmware files.

#### Configuration preview

Copy

#### Download options

Download config files

Configuration.h & Configuration_adv.h

Build firmware.bin

Compile in the cloud

##### Manual build instructions

1. Download the config files above
2. Clone DerAndere-Marlin (https://github.com/DerAndere1/Marlin) repository
3. Replace files in Marlin/ with downloaded configs
4. Build with PlatformIO: pio run -e BTT_OCTOPUS_V1_1
5. Find firmware.bin in .pio/build/

Previous Next

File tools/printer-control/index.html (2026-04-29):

# Printer control panel

Control your Rep5x 5-axis printer via Web Serial connection

Disconnected

Test mode Connect

### Current position

X

0.00

Y

0.00

Z

0.00

C

0.00

B

0.00

### Jog controls

Step:

0.1 1 10 100

mm

X / Y

Y+

X- X+

Y-

Z

Z+ Z-

#### Rotational axes

Step:

1 5 15 45 90

deg

C (Yaw)

C- C+

B (Tilt)

B- B+

Home all Home C/B → 0 Emergency stop

### Temperature

Hotend

-- / --°C

Bed

-- / --°C

Hotend 200 Hotend off Bed 60 Bed off

### Extrusion

Amount:

1 5 10 50

mm

Extrude Retract

Hotend must be at temp (170°C+)

### Console

Clear

[Ready] Printer control initialized

Send

### G-code file

Choose file

Play Stop

No file selected

### Quick commands

Get position Endstop status Report settings Firmware info Save EEPROM Load EEPROM Reset defaults Motors: ON Absolute mode Relative mode Get temps Fan ON

#### 5-axis kinematics

IK: ON Report IK params Calibration: ON Get calibration Reset calibration

#### EEPROM backup

Save all printer settings to a file before flashing firmware, then restore afterwards

Download backup Restore backup

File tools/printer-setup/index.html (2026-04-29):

## Printer setup wizard

Step 1 of 7

1

2

3

4

5

6

7

Connect Prepare Direction C-axis B-axis Z-axis Apply

### Printer setup

Calibrate Z height, axis directions, zero positions and steps/degree. Run this once after building, then again if calibration drifts.

Run this before kinematic calibration.

Accurate Z height and axis positions are required for LC/LB measurement to work correctly.

#### Connect to printer

Not connected

Connect

Connect via USB serial to control and configure your printer.

Test mode (simulate without hardware)

### Prepare printer

Home all axes and move to starting position for calibration.

#### Preparation steps

Disable stepper timeout

Disable software endstops

Home all axes (G28)

Disable IK (G49)

Move to starting position (X100 Y100 C0 B0, Z-50)

Start preparation Skip

Printer ready for calibration

### Direction check

Verify C and B axis motors rotate in the correct direction. Only needed once after initial build or motor changes.

#### C-axis (rotation)

○

Test if the build plate rotates counter-clockwise when viewed from above.

Test C direction Skip (already correct)

Testing...

Correct ✓ Wrong direction

#### C-axis direction is inverted

Fix with one of these options:

Option 1: Change firmware

In Configuration.h, change INVERT_I_DIR from false to true (or vice versa), then recompile and upload.

Option 2: Swap motor wires

Power off, then swap the two wires within one coil pair on the C-axis motor connector (e.g., swap pins 1&2 or pins 3&4).

After fixing, restart the setup wizard to test again.

Restart setup

#### B-axis (tilt)

○

Test if the nozzle tilts to the left when B increases.

Test B direction Skip (already correct)

Testing...

Correct ✓ Wrong direction

#### B-axis direction is inverted

Fix with one of these options:

Option 1: Change firmware

In Configuration.h, change INVERT_J_DIR from false to true (or vice versa), then recompile and upload.

Option 2: Swap motor wires

Power off, then swap the two wires within one coil pair on the B-axis motor connector (e.g., swap pins 1&2 or pins 3&4).

After fixing, restart the setup wizard to test again.

Restart setup

Skip all direction checks

### C-axis calibration

Calibrate rotation axis offset and steps/degree

#### Current target

Nozzle facing forwards

Target: C = 0°

Confirm position Skip

#### Measurements

C = 0° (nozzle forwards) --

C = 360° (full rotation) --

#### C-axis control

0.0

degrees (firmware)

-10° -1° -0.1° +0.1° +1° +10°

Tips:

- At C0: hotend assembly should point towards you
- At C360: hotend assembly should point towards you again

Keyboard controls:

- ← C- → C+ (rotate)
- 1-3 Select step size
- Enter Confirm position
- Space Emergency stop

Step: 1°

### B-axis calibration

Calibrate tilt axis offset and steps/degree

#### Current target

Nozzle pointing straight down

Target: B = 0°

Confirm position Skip

#### Measurements

B = 0° (straight down) --

B = 90° (horizontal left) --

#### B-axis control

0.0

degrees (firmware)

+10° +1° +0.1° -0.1° -1° -10°

Tips:

- For B0: Use a square or look from the side
- For B±90: Nozzle should be parallel to bed

Keyboard controls:

- ← B+ → B- (tilt left/right)
- 1-3 Select step size
- Enter Confirm position
- Space Emergency stop

Step: 1°

### Z-axis calibration

Set the Z=0 position (nozzle touching bed) using the paper test method

#### Paper test method

1. Place a piece of paper on the bed under the nozzle
2. Lower Z slowly until paper has slight resistance when moved
3. Paper should slide with friction, not be stuck
4. Click "Confirm Z0" when the gap feels right

Confirm Z0 Skip

Z0 position recorded: --mm from Z max

#### Z-axis control

0.0

mm (height from bed)

+10mm -10mm

+1mm -1mm

+0.1mm -0.1mm

+0.05mm -0.05mm

Caution:

- Move slowly when close to the bed
- Nozzle should be cold for this test
- If nozzle hits bed, stop and raise Z immediately

Keyboard controls:

- PgUp PgDn Move Z up/down
- 1-4 Select step size
- Enter Confirm position
- Space Emergency stop

Step: 0.1mm

### Apply settings

Review calculations and save to printer

#### Calculated corrections

##### Z-axis

Home offset (M206 Z): --

##### B-axis

Home offset (M206 B): 0.0°

Steps/degree correction: none needed

##### C-axis

Home offset (M206 C): 0.0°

Steps/degree correction: none needed

#### G-code commands

These commands will configure your axis offsets and steps/degree:

; Calculating...

Send to printer Copy to clipboard

Settings saved to printer EEPROM!

Want to fine-tune? Restart calibration:

Restart C-axis Restart B-axis Restart Z-axis

Next steps

Your axes are now calibrated. Continue to the LC/LB Measure to determine your LC and LB parameters.

Previous

Skip to end Next

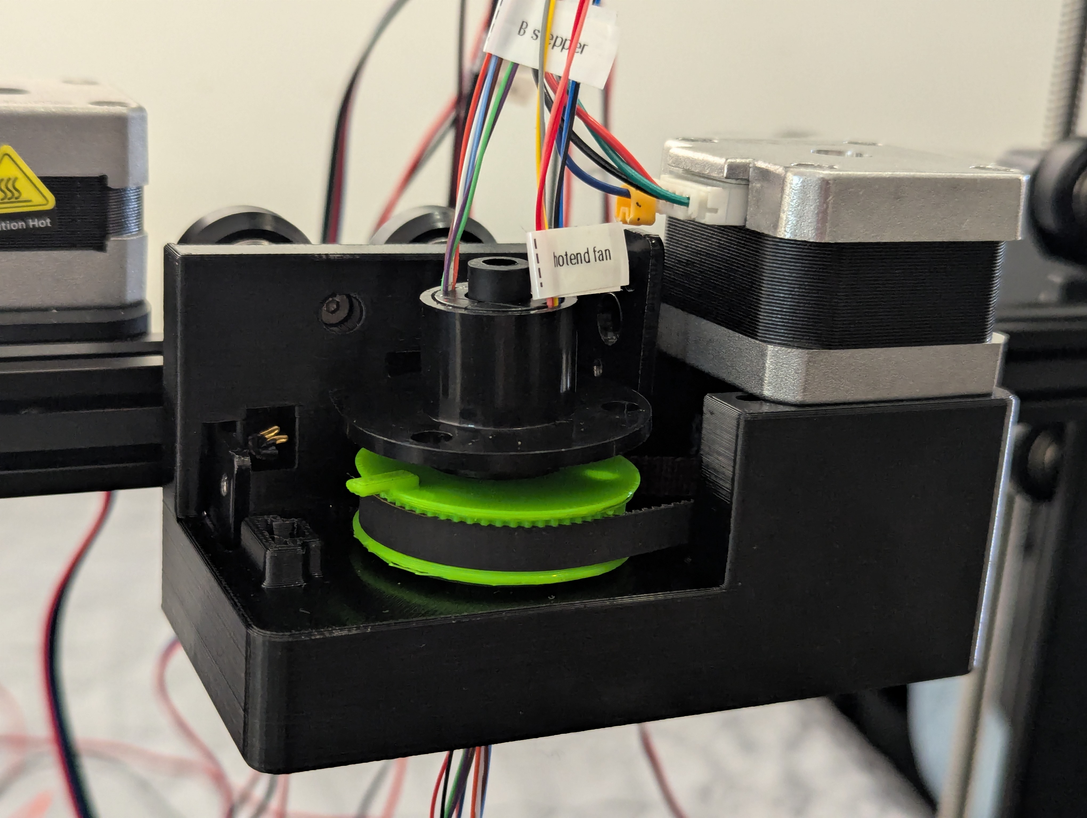
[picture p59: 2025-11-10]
build-guide/images/a-axis-stepper-installed.jpg

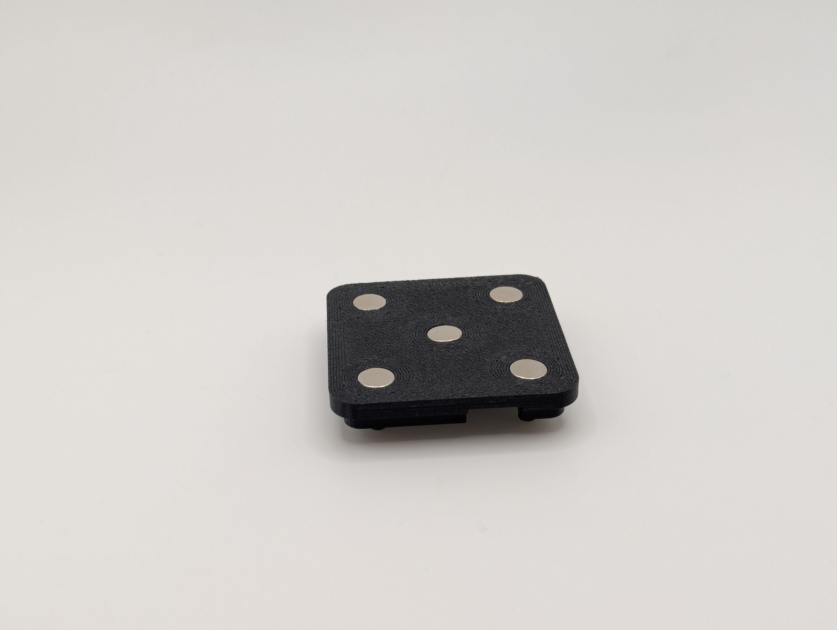
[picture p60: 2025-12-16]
tools/hardware/rep5x-camera/images/camera-magnets-installed.jpg

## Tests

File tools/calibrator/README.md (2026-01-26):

# Rep5x - Calibrator

A calibration tool for finding the error curves of your 5-axis printer across different C and B axis positions. This tool helps identify systematic errors in your printer's kinematic system by measuring the actual nozzle position versus the expected position at multiple points.

## Overview

The calibrator measures position errors at a grid of C and B axis angles:
- **B axis**: 90° to -90° in 15° steps (13 values)
- **C axis**: 0° to 315° in 45° steps (8 values)
- **Total**: 104 measurement points

For each point, the tool:
1. Moves the nozzle to the expected position using inverse kinematics
2. User manually aligns the nozzle with the reference point
3. Records the offset between expected and actual positions
4. Displays the error data in real-time on a graph

## Calibration methods

### Camera method (preferred)

The camera method uses a webcam to visually align the nozzle. For best results, use the [Rep5x camera mount](https://github.com/dennisklappe/Rep5x/tree/main/tools/hardware/rep5x-camera) which provides precise positioning and easy switching between top and side views.

**X/Y calibration (Phase 1)**
- Camera positioned above the bed, looking down
- Crosshair overlay on the camera feed
- User aligns the nozzle tip with the crosshair centre
- Only X and Y offsets are recorded

**Z calibration (Phase 2)**
- Camera repositioned to a side view
- Horizontal line overlay on the camera feed
- User aligns the nozzle tip with the line
- Z offset is recorded

### Cone method (experimental - not yet tested)

The cone method uses a physical calibration cone:
- Position the nozzle at the apex of the cone
- All three axes (X, Y, Z) are calibrated simultaneously
- Faster but may be less precise than the camera method

**Note:** This method has not been extensively tested. The camera method is recommended for reliable results.

## Usage

1. **Select method**: Choose camera or cone calibration
2. **Connect**: Connect to your printer via USB serial
3. **Prepare**:
   - Home all axes
   - Start the camera feed
   - Position the nozzle at the centre of the bed (this becomes the reference point)
4. **Calibrate**:
   - The printer moves to each A/B position
   - Use jog controls to align the nozzle with the reference
   - Press Enter or click "Confirm" when aligned
   - Press Escape or click "Skip" to skip a point
5. **Results**:
   - View error graphs and statistics
   - Export data as CSV or JSON
   - Save results to browser storage

## Keyboard shortcuts (during calibration)

| Key | Action |
|-----|---|
| Arrow keys | Jog X/Y |
| Page Up/Down | Jog Z |
| Enter | Confirm current point |
| Escape | Skip current point |
| Space | Emergency stop |

## Live error graph

The graph displays error curves in real-time as you calibrate:
- **Red line**: X axis error
- **Cyan line**: Y axis error
- **Yellow line**: Z axis error

You can switch between viewing errors by B angle or by C angle using the buttons below the graph.

## Data export

The calibration data can be exported in two formats:

**CSV format**
```
A,B,Expected_X,Expected_Y,Expected_Z,Actual_X,Actual_Y,Actual_Z,Error_X,Error_Y,Error_Z
0,90,100.000,100.000,50.000,100.123,99.987,50.045,0.123,-0.013,0.045
...
```

**JSON format**
```json
{
  "metadata": {
    "timestamp": "2024-01-15T10:30:00.000Z",
    "lc": 0.5,
    "lb": 47.2,
    "referencePosition": {"x": 100, "y": 100, "z": 50}
  },
  "measurements": [...],
  "statistics": {
    "x": {"min": -0.5, "max": 0.8, "avg": 0.1},
    "y": {"min": -0.3, "max": 0.4, "avg": 0.05},
    "z": {"min": -0.2, "max": 0.3, "avg": 0.02}
  }
}
```

## Understanding the results

The error data shows how your printer's kinematic model differs from reality. Common patterns include:

- **Consistent offset**: May indicate LC/LB values need adjustment
- **Sinusoidal pattern on C**: May indicate axis misalignment
- **Progressive error on B**: May indicate LB inaccuracy
- **Random scatter**: Mechanical backlash or measurement error

Use this data to:
1. Refine your LC and LB parameters
2. Identify mechanical issues
3. Create error compensation tables for your slicer

## File structure

```
calibrator/
├── index.html              # Main application
├── README.md               # This file
├── js/
│   ├── app.js              # Main application controller
│   ├── calibration-engine.js  # Data management and IK
│   ├── graph-renderer.js   # Canvas-based error graphs
│   └── camera-overlay.js   # Crosshair and line overlays
└── assets/
    └── (calibration-cone.stl)  # Optional cone model
```

## Requirements

- Modern web browser with WebSerial API support (Chrome, Edge)
- USB connection to printer
- Webcam (for camera method)
- Calibration cone (for cone method)

## Tips

- Run the LC/LB Measure tool first to get accurate LC and LB values
- Ensure the printer is warmed up and stable before calibrating
- Use a small step size (0.1mm) for final adjustments
- Take your time - accuracy is more important than speed
- If a point seems wrong, you can click on the grid to jump back and redo it

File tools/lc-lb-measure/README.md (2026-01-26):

# Rep5x - LC/LB Measure

A web-based tool for measuring the LC and LB kinematic parameters of your Rep5x 5-axis 3D printer.

**Live tool:** https://tools.rep5x.com/lc-lb-measure/

## What are LC and LB?

- **LC (C-axis offset)**: The distance from the C-axis (yaw) rotation centre to the nozzle tip. For the current Rep5x design, this should be **0**.
- **LB (B-axis offset)**: The distance from the B-axis (pitch) rotation centre to the nozzle tip. This varies based on your build (typically ~40-60mm).

These parameters are essential for accurate inverse kinematics calculations, which ensure the nozzle stays at the correct position when rotating.

## Quick start

1. Open `index.html` in Chrome or Edge
2. Select your calibration method (camera or cone)
3. Connect to your printer
4. Follow the step-by-step wizard
5. Save your results

## Calibration methods

### Camera method

Use a USB camera mounted on the print bed facing upward. Align the nozzle with a crosshair overlay for precise measurements.

**Requirements:**
- USB camera (see [Rep5x camera documentation](../hardware/rep5x-camera/))
- 3D printed camera mount

### Cone method

Use a 3D printed calibration cone placed on the bed. Touch the nozzle tip to the cone tip at various angles.

**Requirements:**
- Calibration cone print (see [assets/calibration-cone.stl](assets/calibration-cone.stl))
- No additional hardware needed

## Browser requirements

This tool requires:
- **Chrome 89+** or **Microsoft Edge 89+** (Web Serial API support)
- Camera permissions (for camera method)

Firefox and Safari are not supported due to Web Serial API limitations.

## File structure

```
lc-lb-measure/
├── index.html              # Main application
├── README.md               # This file
├── js/
│   ├── app.js              # Main wizard controller
│   ├── camera-manager.js   # Camera access and crosshair
│   ├── measurement-engine.js # LC/LB calculations
│   ├── connect.js          # Connection step
│   ├── prepare.js          # Preparation step
│   ├── lc-measure.js       # LC measurement step
│   ├── lb-measure.js       # LB measurement step
│   ├── method.js           # Method selection step
│   └── results.js          # Results step
└── assets/
    └── calibration-cone.stl # Printable calibration cone
```

## Support

- **Discord**: [Join our community](https://discord.gg/GNdah82VBg)

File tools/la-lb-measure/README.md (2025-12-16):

# Rep5x - LA/LB Measure

A web-based tool for measuring the LA and LB kinematic parameters of your Rep5x 5-axis 3D printer.

**Live tool:** https://tools.rep5x.com/la-lb-measure/

## What are LA and LB?

- **LA (A-axis offset)**: The distance from the A-axis (yaw) rotation centre to the nozzle tip. For the current Rep5x design, this should be **0**.
- **LB (B-axis offset)**: The distance from the B-axis (pitch) rotation centre to the nozzle tip. This varies based on your build (typically ~40-60mm).

These parameters are essential for accurate inverse kinematics calculations, which ensure the nozzle stays at the correct position when rotating.

## Quick start

1. Open `index.html` in Chrome or Edge
2. Select your calibration method (camera or cone)
3. Connect to your printer
4. Follow the step-by-step wizard
5. Save your results

## Calibration methods

### Camera method

Use a USB camera mounted on the print bed facing upward. Align the nozzle with a crosshair overlay for precise measurements.

**Requirements:**
- USB camera (see [Rep5x camera documentation](../hardware/rep5x-camera/))
- 3D printed camera mount

### Cone method

Use a 3D printed calibration cone placed on the bed. Touch the nozzle tip to the cone tip at various angles.

**Requirements:**
- Calibration cone print (see [assets/calibration-cone.stl](assets/calibration-cone.stl))
- No additional hardware needed

## Browser requirements

This tool requires:
- **Chrome 89+** or **Microsoft Edge 89+** (Web Serial API support)
- Camera permissions (for camera method)

Firefox and Safari are not supported due to Web Serial API limitations.

## File structure

```
la-lb-measure/
├── index.html              # Main application
├── README.md               # This file
├── js/
│   ├── app.js              # Main wizard controller
│   ├── camera-manager.js   # Camera access and crosshair
│   ├── measurement-engine.js # LA/LB calculations
│   ├── connect.js          # Connection step
│   ├── prepare.js          # Preparation step
│   ├── la-measure.js       # LA measurement step
│   ├── lb-measure.js       # LB measurement step
│   ├── method.js           # Method selection step
│   └── results.js          # Results step
└── assets/
    └── calibration-cone.stl # Printable calibration cone
```

## Support

- **Discord**: [Join our community](https://discord.gg/GNdah82VBg)

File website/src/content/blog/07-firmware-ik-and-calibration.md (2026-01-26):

---
title: 'Firmware-side IK and calibration'
description: 'Major firmware update brings inverse kinematics and calibration correction directly into Marlin, plus a new Firmware Builder tool.'
date: 2026-01-26
image: '/images/blog/firmware-builder-tool.webp'
categories: ['firmware', 'tools', 'software']
author:
  name: 'Dennis Klappe'
  designation: 'Masters Student'
  avatar: '/images/team/dennis-klappe.webp'
featured: true
---

Happy 2026! 🎉 It's been a busy start to the year, and I'm excited to share some major updates to the Rep5x project.

## Firmware-side inverse kinematics

Big thanks to **@DerAndere** for making this happen! He implemented the `PENTA_AXIS_HH` (head-head) kinematics in his [Marlin2ForPipetBot](https://github.com/DerAndere1/Marlin/tree/Marlin2ForPipetBot) fork, which we've now integrated into the [Rep5x Marlin firmware](https://github.com/dennisklappe/rep5x-marlin).

Previously, inverse kinematics (IK) calculations had to be done in the slicer or post-processing tools. Now, **IK runs directly in the Marlin firmware**.

This means you can send standard 5-axis G-code with tool tip coordinates and the firmware handles all the complex maths to move the axes correctly. Enable it with `G43.4` in your start G-code, disable with `G49`.

Why does this matter?
- **Simpler workflow** - No need to run G-code through external tools
- **Real-time compensation** - The firmware adjusts on the fly
- **Better compatibility** - Works with any slicer that can output 5-axis coordinates

## Firmware-side calibration correction

The calibrator tool now saves calibration data directly to your printer's EEPROM using the new `M667` command. This stores Fourier coefficients that compensate for mechanical errors in your C and B axes.

Your start G-code now just needs:
```gcode
G49           ; Disable IK during homing
M667 S0       ; Disable calibration during homing
G28           ; Home all axes
; ... heating, purge line, etc ...
G43.4         ; Enable IK
M667 S1       ; Enable calibration
```

And at the end:
```gcode
G49           ; Disable IK before homing
M667 S0       ; Disable calibration
G28 Z         ; Home Z
```

The calibration data persists across reboots, so you only need to calibrate once (or refine it later if needed).

## New: Firmware Builder tool

Building custom Marlin firmware can be intimidating. The new **Firmware Builder** tool at [tools.rep5x.com/firmware-builder](https://tools.rep5x.com/firmware-builder) makes it simple.

<div class="rounded" style="overflow: hidden;">
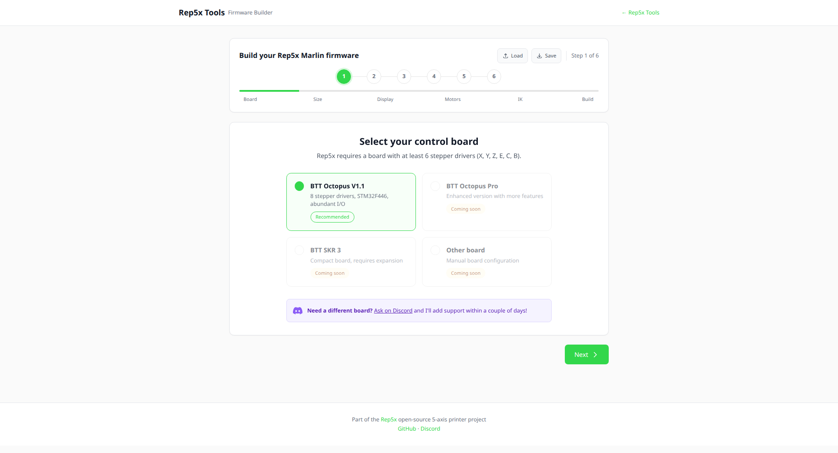
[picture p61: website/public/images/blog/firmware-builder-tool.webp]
Firmware Builder tool

</div>

Select your control board, enter your printer dimensions, configure your motors, and the tool builds ready-to-flash firmware directly in your browser. No need to install PlatformIO or edit configuration files manually.

Currently supports the **BTT Octopus V1.1** with more boards coming soon. If you need support for a different board or want additional features, message me on Discord and I can add it straight away.

## Axis naming: A is now C

We've updated the axis naming to follow industry standards. The rotational axis around Z (yaw) is now called **C-axis** instead of A-axis. This aligns with conventions from ISO 841, the NIST RS274 NGC specification, and LinuxCNC.

The convention: positive C is clockwise rotation of the toolhead relative to the workpiece, when viewed from the workpiece looking from -Z towards +Z.

In practice, this means:
- G-code now uses `C` instead of `A` for the yaw axis
- `B` remains the tilt/pitch axis
- All tools, firmware, and documentation have been updated

If you have existing G-code or configurations using `A`, you'll need to update them to use `C`.

## Tool updates

All the Rep5x tools have received updates:

- **Calibrator** - Now saves calibration to firmware via M667, with support for refining existing calibration
- **LC/LB Measure** - Renamed from LA/LB to match the correct axis naming, now saves measurements directly to printer EEPROM instead of browser storage
- **Vase Generator** - Simplified by removing client-side calibration (now handled by firmware)
- **G-code Viewer** - Updated to work with the new firmware-based IK
- **All tools** - Visual refresh with consistent styling

## What's next

I've seen great progress from people building their own Rep5x printers. If you're thinking about building one yourself or are stuck somewhere along the way, **reach out on Discord or message me directly**. I'm happy to help with CAD modelling, firmware configuration, general troubleshooting, or anything else you might need.

For me personally, the focus now is on better documenting the project and continuing to write and test. Specific goals:

- More control board support in the Firmware Builder
- Improved documentation for the calibration workflow
- Hardware adaptation for the Ender 3 Pro

## Try it out

All tools are available at [tools.rep5x.com](https://tools.rep5x.com). The Firmware Builder is live and ready to use.

Questions or feedback? **[Join our Discord](https://discord.gg/GNdah82VBg)**!

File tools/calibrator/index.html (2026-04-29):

## 5-axis error calibration

Step 1 of 6

1

2

3

4

5

6

Method Connect Prepare XY Z Results

### Select measurement method

Measure position errors across all C and B angles to create an error map. This data can be used to improve print accuracy.

Measures 21 points using sweep calibration: C-axis sweep (0° to 315° at B=0°), then B-axis sweep (0° to ±90° at C=0°). At each point, align the nozzle to the reference and confirm.

#### Camera method

Recommended

Use a USB camera mounted on the bed facing upward. Align the nozzle with a crosshair for X/Y, then reposition camera sideways for Z.

#### Cone method

Alternative

Use a 3D printed calibration cone placed on the bed. Touch the nozzle tip to the cone tip for X, Y, and Z.

Test mode (simulate without hardware)

View camera hardware documentation → (https://github.com/dennisklappe/Rep5x/tree/main/tools/hardware/rep5x-camera)

### Connect to printer

Establish connection to your Rep5x printer via USB serial.

#### Serial connection

Not connected

Connect

Click Connect and select your printer's serial port (usually contains "USB" or "CH340").

#### Camera connection

Not connected

Enable Camera

Test mode enabled

Printer movements will be simulated. Results will not reflect actual machine parameters.

### Prepare printer

Home the printer and set the reference point for measurements.

#### Automatic preparation

Disable stepper timeout

Disable software endstops

Disable inverse kinematics

Home all axes

Move to starting position (X100 Y100 Z50 C0 B0)

Start preparation Skip

Printer ready. Now position the nozzle at the reference point below.

#### Set reference point

Use the jog controls to position the nozzle tip precisely at the camera crosshair or cone tip. This will be the reference point for all measurements.

↻ Camera

Position the nozzle tip to touch the cone tip

XY Movement

Y+

X-

X+

Y-

Z Movement

Z+

Z-

Step size

0.1mm 1mm 10mm

Current position

X: --- Y: --- Z: --- C: --- B: ---

Reference position:

Not set

Skip to Z Confirm reference

### X/Y calibration

0 / 20

0%

↻ Camera

Position nozzle tip at cone apex

Adjust X, Y, and Z until the nozzle touches the cone tip

Current position: C=0° B=0°

X offset

0.000

Y offset

0.000

Z offset

0.000

XY Movement

Y+

X-

X+

Y-

Z Movement

Z+

Z-

Step: 0.1 1 10 mm

X: --- Y: --- Z: --- C: --- B: ---

X error

Y error

Z error

C sweep B sweep

#### Instructions

1. Nozzle moves to expected position
2. Use jog to align with crosshair/line
3. Press Enter or click Confirm

Skip C sweep ↶ Redo previous Confirm (Enter) Skip to Z

### Z calibration

#### Set Z reference point

Position the camera for side view. Align the nozzle tip with the horizontal line, then confirm the reference.

↻ Camera

XY Movement

Y+

X-

X+

Y-

Z Movement

Z+

Z-

0.1 1 10

Reference Z: ---

Confirm Z reference (Enter)

0 / 20

0%

↻ Camera

Current position: C=0° B=0°

Z offset from reference

0.000

X Movement

X-

X+

Z Movement

Z+

Z-

Step: 0.1 1 10 mm

X: --- Y: --- Z: --- C: --- B: ---

Z error

#### Instructions

1. Reposition camera to side view (upright)
2. Camera image is flipped (mounted upside down)
3. Use Z jog to align nozzle with horizontal line
4. Press Enter or click Confirm

Skip Z calibration Confirm (Enter)

### Calibration results

#### C sweep (B=0°)

#### B sweep (C=0°)

X error

Y error

Z error

#### Nozzle position demo

Uncalibrated Calibrated

Both C sweep B sweep Combined Reset

Click to start/stop. Red/orange show drift without calibration, teal/cyan show corrected position. Drag to rotate view.

##### Generate demo G-code

Generate G-code to run on your printer. In uncalibrated mode, nozzle will drift. In calibrated mode, nozzle stays centered.

Center X

Center Y

Center Z

Apply inverse kinematics (software IK)

Download Uncalibrated Download Calibrated

#### X error

Max: ---

Avg: ---

#### Y error

Max: ---

Avg: ---

#### Z error

Max: ---

Avg: ---

Export CSV Export JSON

Save to Firmware

Want to improve accuracy? Run another calibration pass.

Refine calibration

← Previous Next →

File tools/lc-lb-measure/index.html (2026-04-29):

## Kinematic parameter calibration

Step 1 of 6

1

2

3

4

5

6

Method Connect Prepare LC LB Results

### Select measurement method

Determine the LC and LB kinematic parameters for your Rep5x printer. These values are needed for accurate inverse kinematics calculations.

LC = Distance from C-axis rotation centre to nozzle tip. Measured by aligning nozzle to reference at C0°, C90°, C180°, C270°. For Rep5x design, typically close to 0.

LB = Distance from B-axis rotation centre to nozzle tip. Measured by aligning nozzle to reference at B0°, B-90°, B+90°. Typical range: 40-60mm.

#### Camera method

Recommended

Use a USB camera mounted on the print bed facing upward. Align the nozzle with a crosshair overlay for precise measurements.

Requirements:

- USB camera
- 3D printed camera mount

#### Cone method

Alternative

Use a 3D printed calibration cone placed on the bed. Touch the nozzle tip to the cone tip at various angles.

Requirements:

- Calibration cone print

Test mode (simulate without hardware)

View camera hardware documentation → (https://github.com/dennisklappe/Rep5x/tree/main/tools/hardware/rep5x-camera)

### Connect to printer

Establish connection to your Rep5x printer via USB serial.

#### Serial connection

Not connected

Connect

Click Connect and select your printer's serial port (usually contains "USB" or "CH340").

#### Camera connection

Not connected

Enable Camera

#### Measurements to perform

Select which parameters to measure. You can skip one if you only need to verify a single value.

Measure LC (C-axis offset) Measure LB (B-axis offset)

Test mode enabled

Printer movements will be simulated. Results will not reflect actual machine parameters.

### Prepare printer

Home the printer and set the reference point for measurements.

#### Automatic preparation

Disable stepper timeout

Disable software endstops

Disable inverse kinematics

Home all axes

Move to starting position (X100 Y100 Z50 C0 B0)

Start preparation Skip

Printer ready. Now position the nozzle at the reference point below.

#### Set reference point

Use the jog controls to position the nozzle tip precisely at the camera crosshair or cone tip. This will be the reference point for all measurements.

Reconnect camera

Position the nozzle tip to touch the cone tip

XY Movement

Y+

X-

X+

Y-

Z Movement

Z+

Z-

Step size

0.1mm 1mm 10mm

Current position

X: 0.00 Y: 0.00 Z: 0.00 C: 0.0° B: 0.0°

Reference position:

Not set

Confirm reference

The reference point should be where the camera is focused (typically the bed surface or a fixed point). This point remains constant while rotating the C and B axes to measure LC and LB.

### LC measurement (C-axis)

Align the nozzle to the reference point at C0°, C90°, C180°, C270°. The distance moved reveals LC.

Camera view

Align nozzle tip with the centre crosshair Reconnect

Cone alignment

Position the nozzle tip to touch the cone tip

IK-assisted positioning

Enable

Auto-position using IK when rotating

LC:

LB:

Z safety lift

Z raised before rotating C-axis

Offset: mm

#### Instructions

Position the nozzle tip at your reference point (camera crosshair or cone tip) with C-axis at 0°.

Current angle: C = 0° Confirm position

#### Measurement progress

C = 0° Waiting...

C = 90° Waiting...

C = 180° Waiting...

C = 270° Waiting...

LC result: 0.00 mm

Redo with measured LC

#### Movement controls

XY Movement

Y+

X-

X+

Y-

Z Movement

Z+

Z-

C/B Rotation

C- C+

B- B+

Step size

0.1mm 1mm 10mm | 1° 10° 90°

Current position

X: 0.00 Y: 0.00 Z: 0.00 C: 0.0° B: 0.0°

### LB measurement (B-axis)

Align the nozzle to the reference point at B0°, B-90°, B+90°. The distance moved reveals LB.

Camera view

Align nozzle tip with the centre crosshair Reconnect

Cone alignment

Position the nozzle tip to touch the cone tip

IK-assisted positioning

Enable

Auto-position using IK when rotating

LC:

LB:

Z safety lift

Z raised before rotating B-axis

Offset: mm

#### Instructions

Position the nozzle tip at your reference point with B-axis at 0°.

Current angle: B = 0° Confirm position

#### Measurement progress

B = 0° Waiting...

B = -90° Waiting...

C = 180°, B = +90° Waiting...

LB result: 0.00 mm

Redo with measured LB

#### Movement controls

XY Movement

Y+

X-

X+

Y-

Z Movement

Z+

Z-

C/B Rotation

C- C+

B- B+

Step size

0.1mm 1mm 10mm | 1° 10° 90°

Current position

X: 0.00 Y: 0.00 Z: 0.00 C: 0.0° B: 0.0°

### Measurement complete

Your kinematic parameters have been determined.

LC (C-axis offset)

0.00

millimetres

LB (B-axis offset)

0.00

millimetres

#### Save results

Send to printer (save to EEPROM) Copy values to clipboard

Values saved to printer

Click "Send to printer" to store LC/LB values in your printer's EEPROM. The firmware will automatically apply inverse kinematics during printing.

Previous Next

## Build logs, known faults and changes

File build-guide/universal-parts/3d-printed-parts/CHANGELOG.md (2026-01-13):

# Rep5x - 3D printed parts changelog

Version history and changes for Rep5x 3D printed components. This log helps builders understand what changed between versions and decide whether to reprint parts.

---

## Version 1.1.1 (January 2026)

### slip-ring-holder v1.1.1
- **Updated**: Shortened overall length for easier fit between carriage mount and slip ring
- **Reason**: Improved clearance and easier assembly with v1.1.x carriage mounts
- **Compatibility**: Direct replacement for v1.1.0. Requires v1.1.x carriage mount design (not compatible with v1.0.0 Ender 5 Pro carriage mount)

---

## Version 1.1.0 (November 2025)

### b-arm v1.1.0
- **Added**: Cable routing slit in the slip ring cable hole
- **Reason**: Allows easier installation/replacement of B-arm without disconnecting hotend and stepper cables
- **Compatibility**: Direct replacement for v1.0.0

### A-driven-pulley v1.1.0
- **Updated**: Shaft diameter slightly reduced for better bearing fit
- **Reason**: Improved fit tolerance with 61804 bearings
- **Compatibility**: Direct replacement for v1.0.0

### b-driven-pulley v1.1.0
- **Removed**: Fan mount holes
- **Reason**: Hotend fan is now directly mounted to hotend assembly, eliminating need for additional mounting points
- **Compatibility**: Direct replacement for v1.0.0

### slip-ring-holder v1.1.0
- **Updated**: Redesigned slipring mounting component
- **Replaces**: slip-ring-holder v1.0.0
- **Reason**: Redesigned to fit v1.1.x carriage mount design
- **Compatibility**: Requires v1.1.x carriage mount design (not compatible with v1.0.0 Ender 5 Pro carriage mount)

### B_switch_cover v1.1.0
- **Removed**: No longer required in v1.1.0 design
- **Reason**: Hot glue positioning method eliminates need for 3D printed cover
- **Compatibility**: Use hot glue to position switch directly

---

## Version 1.0.0 (October 2025)

Initial release of all Rep5x 3D printed components.

### Components included:
- A-driven-pulley v1.0.0
- b-driven-pulley v1.0.0
- B_arm v1.0.0
- B_switch_cover v1.0.0
- slip-ring-holder v1.0.0
- spacer-3mm v1.0.0
- fan-mount v1.0.0
- fanmount v1.0.0
- hotend-spacer v1.0.0
- carriage-mount v1.0.0 (Ender 5 Pro)

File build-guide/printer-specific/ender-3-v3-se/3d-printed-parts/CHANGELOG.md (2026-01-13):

# Ender 3 V3 SE - 3D printed parts changelog

Version history and changes for Ender 3 V3 SE specific 3D printed components.

---

## Version 1.1.1 (January 2026)

### carriage-mount v1.1.1
- **Updated**: Widened yaw stepper bolt holes to accommodate M3 washers (7mm OD)
- **Fixed**: Corrected spacing between locking holes to properly align with stepper mounting holes for improved tensioning
- **Reason**: Previous version caused deformation at yaw stepper connection due to insufficient clearance; locking holes were misaligned with stepper holes preventing proper tensioning
- **Requires**: 4x M3 washers (7mm outer diameter) - added to BOM
- **Compatibility**: Direct replacement for v1.1.0. Use with slip-ring-holder v1.1.1 from universal parts
- **Future**: Could benefit from a dedicated tensioning system in a future revision

---

## Version 1.1.0 (November 2025)

### carriage-mount v1.1.0
- Initial Ender 3 V3 SE carriage mount design

### x-endstop v1.1.0
- X-axis endstop mount for Ender 3 V3 SE

### z-endstop v1.1.0
- Z-axis endstop mount for Ender 3 V3 SE

### extruder-mount v1.1.0
- External Bowden extruder mount for Ender 3 V3 SE

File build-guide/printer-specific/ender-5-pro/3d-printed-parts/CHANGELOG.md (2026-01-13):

# Ender 5 Pro - 3D printed parts changelog

Version history and changes for Ender 5 Pro specific 3D printed components.

---

## Version 1.0.0 (October 2025)

### carriage-mount v1.0.0
- Initial Ender 5 Pro carriage mount design
- **Compatibility**: Use with slip-ring-holder v1.0.0 from universal parts

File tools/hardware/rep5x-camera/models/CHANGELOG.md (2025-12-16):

# Rep5x camera mount - 3D printed parts changelog

Version history and changes for Rep5x camera mount components. This log helps builders understand what changed between versions and decide whether to reprint parts.

---

## Version 1.0.0 (December 2025)

Initial release of all Rep5x camera mount components.

### Components included:
- camera-mount-bottom v1.0.0
- camera-mount-top v1.0.0
- camera-mount-z-axis v1.0.0

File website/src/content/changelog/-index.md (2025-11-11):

---
title: "Changelog"
meta_title: ""
description: "Rep5x project development changelog and version history"
image: ""

hero:
  title: "Rep5x Development Changelog"
  description: "Track the development progress of Rep5x open-source 5-axis printing technology through version updates and improvements."

list:
  - version: "v0.3.0"
    title: "Firmware Improvements"
    date: "October 2025"
    image: ""
    content: |
      - Enhanced inverse kinematics calculations for better precision
      - Added support for dual-board configuration (2x Ender boards)
      - Improved calibration routines for A and B axes
      - Fixed stepper driver compatibility issues
  - version: "v0.2.0"
    title: "Hardware Refinement"
    date: "September 2025"
    image: ""
    content: |
      - Redesigned print head mount for better rigidity
      - Updated electronics housing design
      - Improved cable management system
      - Added compatibility for Ender 5 Pro base printer
  - version: "v0.1.0"
    title: "Initial Release"
    date: "September 2025"
    image: ""
    content: |
      - First public release of Rep5x design files
      - Basic 5-axis retrofit system for testing
      - Initial firmware with inverse kinematics support
      - Community documentation and build guides
---

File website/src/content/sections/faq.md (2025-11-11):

---
# Our Customers
title: "Frequently Asked Questions"
description: "Common questions about Rep5x open-source 5-axis 3D printing technology and how to get started with the project."
badge: "FAQ"

exclusive_open: true
exclusive_open_group: "faq"

# FAQ List
list:
  - title: What is Rep5x and how does it work?
    description: Rep5x is an open-source retrofit system that adds 5-axis capability to existing 3D printers. It uses two additional rotational axes (yaw and pitch) in the print head to enable printing complex geometries without supports and achieve better surface quality.
    active: true
  - title: Which printers are compatible with Rep5x?
    description: Rep5x currently supports the Ender 5 Pro and Ender 3 V3 SE with working prototypes. The project uses a modular design approach to support additional printer platforms through community contributions.
  - title: Do I need special firmware or software?
    description: Yes, Rep5x requires firmware modifications to handle the additional axes and inverse kinematics calculations. We provide modified Marlin firmware and configuration.
  - title: How difficult is it to build a Rep5x system?
    description: The build requires intermediate 3D printing and electronics knowledge. Most retrofit parts can be printed on your existing 3D printer. The project is currently in beta stage with documentation available. Community support is available through our [Discord server](https://discord.gg/75Hy5dMwTJ).
  - title: What are the benefits of 5-axis printing?
    description: 5-axis printing eliminates the need for support structures in most cases, reduces material waste, improves surface finish quality, and enables printing of complex geometries that are impossible with traditional 3-axis methods.
  - title: Is Rep5x completely free and open source?
    description: Yes, all Rep5x hardware designs, firmware, and documentation are released under the GPL v3 License. You can build, modify, and contribute to Rep5x systems. The only costs are for components and materials needed for assembly.
---

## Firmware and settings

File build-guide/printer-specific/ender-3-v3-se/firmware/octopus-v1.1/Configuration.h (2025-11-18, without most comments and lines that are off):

#pragma once
#define CONFIGURATION_H_VERSION 02010300
#define STRING_CONFIG_H_AUTHOR "(MarlinFirmware)" // Original author or contributor.
  #define MOTHERBOARD BOARD_BTT_OCTOPUS_V1_1
#define SERIAL_PORT -1
#define BAUDRATE 250000
#define X_DRIVER_TYPE  TMC2208
#define Y_DRIVER_TYPE  TMC2208
#define Z_DRIVER_TYPE  TMC2208
#define I_DRIVER_TYPE  TMC2208
#define J_DRIVER_TYPE  TMC2208
#define E0_DRIVER_TYPE TMC2208
  #define AXIS4_NAME 'A' // :['A', 'B', 'C', 'U', 'V', 'W']
  #define AXIS4_ROTATES
  #define AXIS5_NAME 'B' // :['B', 'C', 'U', 'V', 'W']
  #define AXIS5_ROTATES
#define EXTRUDERS 1
#define DEFAULT_NOMINAL_FILAMENT_DIA 1.75
#define TEMP_SENSOR_0 1
#define TEMP_SENSOR_1 0
#define TEMP_SENSOR_2 0
#define TEMP_SENSOR_3 0
#define TEMP_SENSOR_4 0
#define TEMP_SENSOR_5 0
#define TEMP_SENSOR_6 0
#define TEMP_SENSOR_7 0
#define TEMP_SENSOR_BED 1
#define TEMP_SENSOR_PROBE 0
#define TEMP_SENSOR_CHAMBER 0
#define TEMP_SENSOR_COOLER 0
#define TEMP_SENSOR_BOARD 0
#define TEMP_SENSOR_SOC 0
#define TEMP_SENSOR_REDUNDANT 0
#define DUMMY_THERMISTOR_998_VALUE  25
#define DUMMY_THERMISTOR_999_VALUE 100
#if TEMP_SENSOR_IS_MAX_TC(0)
  #define MAX31865_SENSOR_OHMS_0      100 // (Ω) Typically 100 or 1000 (PT100 or PT1000)
  #define MAX31865_CALIBRATION_OHMS_0 430 // (Ω) Typically 430 for Adafruit PT100; 4300 for Adafruit PT1000
#endif
#if TEMP_SENSOR_IS_MAX_TC(1)
  #define MAX31865_SENSOR_OHMS_1      100
  #define MAX31865_CALIBRATION_OHMS_1 430
#endif
#if TEMP_SENSOR_IS_MAX_TC(2)
  #define MAX31865_SENSOR_OHMS_2      100
  #define MAX31865_CALIBRATION_OHMS_2 430
#endif
#if TEMP_SENSOR_IS_MAX_TC(BED)
  #define MAX31865_SENSOR_OHMS_BED      100
  #define MAX31865_CALIBRATION_OHMS_BED 430
#endif
#if HAS_E_TEMP_SENSOR
  #define TEMP_RESIDENCY_TIME         10  // (seconds) Time to wait for hotend to "settle" in M109
  #define TEMP_WINDOW                  1  // (°C) Temperature proximity for the "temperature reached" timer
  #define TEMP_HYSTERESIS              3  // (°C) Temperature proximity considered "close enough" to the target
#endif
#if TEMP_SENSOR_BED
  #define TEMP_BED_RESIDENCY_TIME     10  // (seconds) Time to wait for bed to "settle" in M190
  #define TEMP_BED_WINDOW              1  // (°C) Temperature proximity for the "temperature reached" timer
  #define TEMP_BED_HYSTERESIS          3  // (°C) Temperature proximity considered "close enough" to the target
#endif
#if TEMP_SENSOR_CHAMBER
  #define TEMP_CHAMBER_RESIDENCY_TIME 10  // (seconds) Time to wait for chamber to "settle" in M191
  #define TEMP_CHAMBER_WINDOW          1  // (°C) Temperature proximity for the "temperature reached" timer
  #define TEMP_CHAMBER_HYSTERESIS      3  // (°C) Temperature proximity considered "close enough" to the target
#endif
#if TEMP_SENSOR_REDUNDANT
  #define TEMP_SENSOR_REDUNDANT_SOURCE    E1  // The sensor that will provide the redundant reading.
  #define TEMP_SENSOR_REDUNDANT_TARGET    E0  // The sensor that we are providing a redundant reading for.
  #define TEMP_SENSOR_REDUNDANT_MAX_DIFF  10  // (°C) Temperature difference that will trigger a print abort.
#endif
#define HEATER_0_MINTEMP   5
#define HEATER_1_MINTEMP   5
#define HEATER_2_MINTEMP   5
#define HEATER_3_MINTEMP   5
#define HEATER_4_MINTEMP   5
#define HEATER_5_MINTEMP   5
#define HEATER_6_MINTEMP   5
#define HEATER_7_MINTEMP   5
#define BED_MINTEMP        5
#define CHAMBER_MINTEMP    5
#define HEATER_0_MAXTEMP 275
#define HEATER_1_MAXTEMP 275
#define HEATER_2_MAXTEMP 275
#define HEATER_3_MAXTEMP 275
#define HEATER_4_MAXTEMP 275
#define HEATER_5_MAXTEMP 275
#define HEATER_6_MAXTEMP 275
#define HEATER_7_MAXTEMP 275
#define BED_MAXTEMP      150
#define CHAMBER_MAXTEMP  60
#define HOTEND_OVERSHOOT 15   // (°C) Forbid temperatures over MAXTEMP - OVERSHOOT
#define BED_OVERSHOOT    10   // (°C) Forbid temperatures over MAXTEMP - OVERSHOOT
#define COOLER_OVERSHOOT  2   // (°C) Forbid temperatures closer than OVERSHOOT
#define PIDTEMP           // See the PID Tuning Guide at https://reprap.org/wiki/PID_Tuning
#define PID_MAX  255      // Limit hotend current while PID is active (see PID_FUNCTIONAL_RANGE below); 255=full current
#define PID_K1     0.95   // Smoothing factor within any PID loop
    #define DEFAULT_Kp  22.20
    #define DEFAULT_Ki   1.08
    #define DEFAULT_Kd 114.00
#define MAX_BED_POWER 255 // limits duty cycle to bed; 255=full current
#define MAX_CHAMBER_POWER 255 // limits duty cycle to chamber heater; 255=full current
  #define PID_FUNCTIONAL_RANGE 20 // If the temperature difference between the target temperature and the actual temperature
#define PREVENT_COLD_EXTRUSION
#define EXTRUDE_MINTEMP 170
#define PREVENT_LENGTHY_EXTRUDE
#define EXTRUDE_MAXLENGTH 650
#define THERMAL_PROTECTION_HOTENDS // Enable thermal protection for all extruders
#define THERMAL_PROTECTION_BED     // Enable thermal protection for the heated bed
#define THERMAL_PROTECTION_CHAMBER // Enable thermal protection for the heated chamber
#define THERMAL_PROTECTION_COOLER  // Enable thermal protection for the laser cooling
#define ENDSTOPPULLUPS
#define X_MIN_ENDSTOP_HIT_STATE HIGH
#define X_MAX_ENDSTOP_HIT_STATE HIGH
#define Y_MIN_ENDSTOP_HIT_STATE HIGH
#define Y_MAX_ENDSTOP_HIT_STATE HIGH
#define Z_MIN_ENDSTOP_HIT_STATE HIGH
#define Z_MAX_ENDSTOP_HIT_STATE LOW
#define I_MIN_ENDSTOP_HIT_STATE HIGH
#define I_MAX_ENDSTOP_HIT_STATE HIGH
#define J_MIN_ENDSTOP_HIT_STATE LOW
#define J_MAX_ENDSTOP_HIT_STATE LOW
#define K_MIN_ENDSTOP_HIT_STATE HIGH
#define K_MAX_ENDSTOP_HIT_STATE HIGH
#define U_MIN_ENDSTOP_HIT_STATE HIGH
#define U_MAX_ENDSTOP_HIT_STATE HIGH
#define V_MIN_ENDSTOP_HIT_STATE HIGH
#define V_MAX_ENDSTOP_HIT_STATE HIGH
#define W_MIN_ENDSTOP_HIT_STATE HIGH
#define W_MAX_ENDSTOP_HIT_STATE HIGH
#define Z_MIN_PROBE_ENDSTOP_HIT_STATE HIGH
#define DEFAULT_AXIS_STEPS_PER_UNIT   { 80, 80, 400, 26.666, 26.68, 415 }
#define EDITABLE_STEPS_PER_UNIT
#define DEFAULT_MAX_FEEDRATE          { 500, 500, 600, 3600, 3600, 45 }  // Units: mm/s
#define DEFAULT_MAX_ACCELERATION      { 3000, 3000, 500, 1000, 1000, 10000 }
#define DEFAULT_ACCELERATION          3000    // X, Y, Z and E acceleration for printing moves
#define DEFAULT_RETRACT_ACCELERATION  3000    // E acceleration for retracts
#define DEFAULT_TRAVEL_ACCELERATION   3000    // X, Y, Z acceleration for travel (non printing) moves
  #define JUNCTION_DEVIATION_MM 0.013 // (mm) Distance from real junction edge
  #define JD_HANDLE_SMALL_SEGMENTS    // Use curvature estimation instead of just the junction angle
#define NOZZLE_TO_PROBE_OFFSET { 10, 10, 0 }
#define PROBING_TOOL 0
#define PROBING_MARGIN 10
#define XY_PROBE_FEEDRATE    (133*60) // (mm/min)
#define Z_PROBE_FEEDRATE_FAST  (4*60) // (mm/min)
#define Z_PROBE_FEEDRATE_SLOW (Z_PROBE_FEEDRATE_FAST / 2) // (mm/min)
#define Z_CLEARANCE_DEPLOY_PROBE   10 // (mm) Z Clearance for Deploy/Stow
#define Z_CLEARANCE_BETWEEN_PROBES  5 // (mm) Z Clearance between probe points
#define Z_CLEARANCE_MULTI_PROBE     5 // (mm) Z Clearance between multiple probes
#define Z_PROBE_ERROR_TOLERANCE     3 // (mm) Tolerance for early trigger (<= -probe.offset.z + ZPET)
#define Z_PROBE_LOW_POINT          -2 // (mm) Farthest distance below the trigger-point to go before stopping
#define X_ENABLE_ON LOW
#define Y_ENABLE_ON LOW
#define Z_ENABLE_ON LOW
#define E_ENABLE_ON LOW // For all extruders
#define I_ENABLE_ON LOW
#define J_ENABLE_ON LOW
#define DISABLE_OTHER_EXTRUDERS   // Keep only the active extruder enabled
#define INVERT_X_DIR false
#define INVERT_Y_DIR false
#define INVERT_Z_DIR false
#define INVERT_I_DIR true
#define INVERT_J_DIR false
#define INVERT_E0_DIR false
#define INVERT_E1_DIR false
#define INVERT_E2_DIR false
#define INVERT_E3_DIR false
#define INVERT_E4_DIR false
#define INVERT_E5_DIR false
#define INVERT_E6_DIR false
#define INVERT_E7_DIR false
#define X_HOME_DIR 1
#define Y_HOME_DIR 1
#define Z_HOME_DIR 1
#define I_HOME_DIR 1
#define J_HOME_DIR -1
#define X_BED_SIZE 200
#define Y_BED_SIZE 200
#define X_MIN_POS 0
#define Y_MIN_POS 0
#define Z_MIN_POS 0
#define X_MAX_POS X_BED_SIZE
#define Y_MAX_POS Y_BED_SIZE
#define Z_MAX_POS 174.6
#define I_MIN_POS -360
#define I_MAX_POS 360
#define J_MIN_POS -146
#define J_MAX_POS 146
#define MIN_SOFTWARE_ENDSTOPS
  #define MIN_SOFTWARE_ENDSTOP_X
  #define MIN_SOFTWARE_ENDSTOP_Y
  #define MIN_SOFTWARE_ENDSTOP_Z
  #define MIN_SOFTWARE_ENDSTOP_I
  #define MIN_SOFTWARE_ENDSTOP_J
  #define MIN_SOFTWARE_ENDSTOP_K
  #define MIN_SOFTWARE_ENDSTOP_U
  #define MIN_SOFTWARE_ENDSTOP_V
  #define MIN_SOFTWARE_ENDSTOP_W
#define MAX_SOFTWARE_ENDSTOPS
  #define MAX_SOFTWARE_ENDSTOP_X
  #define MAX_SOFTWARE_ENDSTOP_Y
  #define MAX_SOFTWARE_ENDSTOP_Z
  #define MAX_SOFTWARE_ENDSTOP_I
  #define MAX_SOFTWARE_ENDSTOP_J
  #define MAX_SOFTWARE_ENDSTOP_K
  #define MAX_SOFTWARE_ENDSTOP_U
  #define MAX_SOFTWARE_ENDSTOP_V
  #define MAX_SOFTWARE_ENDSTOP_W
#define MANUAL_Y_HOME_POS 240
#define MANUAL_I_HOME_POS 177
#define HOMING_FEEDRATE_MM_M { (50*60), (50*60), (15*60), (90*60), (45*60) }
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

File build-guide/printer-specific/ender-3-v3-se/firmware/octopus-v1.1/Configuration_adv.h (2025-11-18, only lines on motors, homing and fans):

#define E0_AUTO_FAN_PIN -1
#define E1_AUTO_FAN_PIN -1
#define E2_AUTO_FAN_PIN -1
#define E3_AUTO_FAN_PIN -1
#define E4_AUTO_FAN_PIN -1
#define E5_AUTO_FAN_PIN -1
#define E6_AUTO_FAN_PIN -1
#define E7_AUTO_FAN_PIN -1
#define CHAMBER_AUTO_FAN_PIN -1
#define COOLER_AUTO_FAN_PIN -1
#define HOMING_BUMP_MM      { 5, 5, 3, 5, 2 }       // (linear=mm, rotational=°) Backoff from endstops after first bump
#define HOMING_BUMP_DIVISOR { 2, 2, 4, 2, 4 }       // Re-Bump Speed Divisor (Divides the Homing Feedrate)
#define HOMING_BACKOFF_POST_MM { 2, 2, 2, 2, 2 }  // (linear=mm, rotational=°) Backoff from endstops after homing
#define MICROSTEP_MODES { 16, 16, 16, 16, 16, 16 } // [1,2,4,8,16]
#define ADVANCED_PAUSE_FEATURE
  #define ADVANCED_PAUSE_PURGE_FEEDRATE        3  // (mm/s) Extrude feedrate (after loading). Should be slower than load feedrate.
  #define ADVANCED_PAUSE_PURGE_LENGTH         50  // (mm) Length to extrude after loading.
  #define ADVANCED_PAUSE_RESUME_PRIME          0  // (mm) Extra distance to prime nozzle after returning from park.
    #define X_CURRENT       800        // (mA) RMS current. Multiply by 1.414 for peak current.
    #define X_CURRENT_HOME  X_CURRENT  // (mA) RMS current for homing. (Typically lower than *_CURRENT.)
    #define X_MICROSTEPS     16        // 0..256
    #define Y_CURRENT       800
    #define Y_CURRENT_HOME  Y_CURRENT
    #define Y_MICROSTEPS     16
    #define Z_CURRENT       800
    #define Z_CURRENT_HOME  Z_CURRENT
    #define Z_MICROSTEPS     16
    #define I_CURRENT      800
    #define I_CURRENT_HOME I_CURRENT
    #define I_MICROSTEPS    16
    #define J_CURRENT      800
    #define J_CURRENT_HOME J_CURRENT
    #define J_MICROSTEPS    16
    #define E0_CURRENT      800
    #define E0_MICROSTEPS    16
  #define X_HYBRID_THRESHOLD     100  // [mm/s]
  #define X2_HYBRID_THRESHOLD    100
  #define Y_HYBRID_THRESHOLD     100
  #define Y2_HYBRID_THRESHOLD    100
  #define Z_HYBRID_THRESHOLD       3
  #define Z2_HYBRID_THRESHOLD      3
  #define Z3_HYBRID_THRESHOLD      3
  #define Z4_HYBRID_THRESHOLD      3
  #define I_HYBRID_THRESHOLD       3  // [linear=mm/s, rotational=°/s]
  #define J_HYBRID_THRESHOLD       3  // [linear=mm/s, rotational=°/s]
  #define K_HYBRID_THRESHOLD       3  // [linear=mm/s, rotational=°/s]
  #define U_HYBRID_THRESHOLD       3  // [mm/s]
  #define V_HYBRID_THRESHOLD       3
  #define W_HYBRID_THRESHOLD       3
  #define E0_HYBRID_THRESHOLD     30
  #define E1_HYBRID_THRESHOLD     30
  #define E2_HYBRID_THRESHOLD     30
  #define E3_HYBRID_THRESHOLD     30
  #define E4_HYBRID_THRESHOLD     30
  #define E5_HYBRID_THRESHOLD     30
  #define E6_HYBRID_THRESHOLD     30
  #define E7_HYBRID_THRESHOLD     30

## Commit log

2025-10-27 Add STEP files and organize parts by format
    [A-driven-pulley.3mf, A-driven-pulley.step, B-driven-pulley 2.3mf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]
2025-11-10 Update/assembly guide restructure docs (#2)
    * Add assembly guide and restructure documentation
    * Add Ender 3 V3 SE support and update to v1.1.0 parts
    * Finalize documentation restructure and build instructions
    [A-driven-pulley.3mf, A-driven-pulley.step, A-driven-pulley_v1.0.0.3mf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]
2025-11-11 Feature/website (#3)
    * Add Rep5x website
    * Add build instructions
    * Fix changelog to use WebP images from blog folder
    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
    [extruder-mount_v1.1.0.3mf, extruder-mount_v1.1.0.step]
2025-11-12 Add blog post about new website and assembly instructions (#4)
2025-11-18 Update E3V3SE firmware configuration (#7)
    [Configuration.h, Configuration_adv.h]
2025-11-18 Feature/vase generator + gcode viewer (#8)
    * Add blog post about new website and assembly instructions
    * Improve build instructions + purchase links
    * Add website link to README + fix file path
    * Create 5-axis G-code previewer with proper nozzle visualization
    - Add complete G-code previewer for 5-axis printing
    - Implement direct coordinate mapping (G-code X→Three.js X, Y→Z, Z→Y)
    - Fix nozzle orientation with correct A/B axis rotations
    - Position nozzle tip at group origin for stable rotation tracking
    - Add red cone tip that stays exactly on G-code path during 5-axis movements
    - Support animation controls, progress tracking, and file drag/drop
    - Include inverse kinematics reverser f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
2025-11-19 Tools/vase generator improvements (#11)
    * inverse B
    * clean up viewer UI and remove old previewer
    * set extrusion to relative
    * fix Y-axis direction in viewer
    * set default LB parameter to 47.9
2025-11-19 Fix/e3v3se y axis homing (#12)
    * Fix Y-axis homing configuration for Ender 3 V3 SE
    * Reorganize slicing files to dedicated folder
    * Improve start and end gcode
2025-12-08 Add b-arm v1.1.0 with cable routing slit (#14)
    [B_arm_v1.0.0.3mf, B_arm_v1.0.0.step, FullAssem_v1.1.0.f3z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]
2025-12-16 Tools/adding and improving tools (#15)
    * Tools/fix b axis inversion (#13)
    * Restructure G-code viewer and add collision detection
    * Refactor animation engine into smaller modules
    * Clean up mushroom vase generator code
    * Clean up elbow pipe vase generator code
    * Improve mushroom cap toolpath transitions
    * Add spatial partitioning to collision detection
    * Move camera-manager to shared folder
    * Add tools blog post and update website menu
    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
    [Configuration.h, Configuration_adv.h, calibration-cone.stl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]
2026-01-05 Fix IK reverser to track modal A/B axis values (#17)
2026-01-13 Add E3V3SE carriage-mount v1.1.1 and slip-ring-holder v1.1.1 (#18)
    [carriage-mount_v1.0.0.3mf, carriage-mount_v1.0.0.step, carriage-mount_v1.1.0.3mf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]
2026-01-19 Tools/calibration workflow (#22)
    * Fix IK reverser to track modal A/B axis values
    * Add calibrator and gcode-corrector tools
    New tools:
    - Calibrator: Interactive A/B sweep calibration with camera/cone methods
    - G-code Corrector: Apply IK and calibration corrections to G-code files
    Other improvements:
    - G-code Viewer: Auto-detect and reverse corrections for accurate display
    - Refactor IK and A-axis optimizer to /shared
    - Add shared calibration components (corrector, visualizers, graph renderer)
    - Update tools README and index page
    Establishes complete calibration workflow: calibrate → correct → view
2026-01-19 Add Ender 3 Pro printer-specific documentation (#20)
    [carriage-mount_v1.1.1.3mf, carriage-mount_v1.1.1.step]
2026-01-20 Tools/firmware builder (#24)
    * Add firmware build workflow for cloud compilation
    * Update workflow with all customization options (dimensions, homing, drivers, steps, directions, IK, neopixel)
    * Add firmware builder tool (worker, frontend, config generator)
    * Fix neopixel color and IK offset sed patterns
    * Add config file storage to R2 and show build ID in UI for troubleshooting
    * Add IK enabled toggle support to firmware build workflow
    Workflow now supports ikEnabled customization option to control
    DEFAULT_TOOL_CENTERPOINT_CONTROL in the compiled firmware.
    * Add config import/export and auto-save functionality
    * Consolidate firmware docs to tool-first approach
    * Add Firmware Builde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
    [Configuration.h, Configuration_adv.h]
2026-01-26 Firmware/ik calculations (#25)
    * Rename A-axis to C-axis and LA to LC across all tools
    - Rename la-lb-measure/ directory to lc-lb-measure/
    - Rename a-axis.js to c-axis.js, a-axis-optimizer.js to c-axis-optimizer.js
    - Update all variable names, function names, class names (e.g. StepAAxis → StepCAxis)
    - Update G-code commands from A to C axis
    - Update UI labels, comments, and documentation
    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
    [C-driven-pulley_v1.1.0.3mf, C-driven-pulley_v1.1.0.step, calibration-cone.stl]
2026-01-26 Add blog post: firmware-side IK and calibration (#26)
2026-01-27 Fix calibrator and printer-setup tool issues (#29)
2026-01-27 Refactor/tools cleanup (#31)
    * Refactor gcode-viewer: extract CSS and JS to separate files
    * Refactor calibrator: extract CSS to separate file
    * Refactor firmware-builder: extract CSS to separate file
    * Refactor lc-lb-measure: extract CSS to separate file
    * Refactor printer-control: extract CSS to separate file
    * Refactor printer-setup: extract CSS to separate file
    * Refactor gcode-corrector: extract CSS to separate file
    * Consolidate duplicated CSS patterns to shared/styles.css
    * Add shared JS utilities: file-downloader, drag-drop, toast notifications
    * Add shared StepConnectBase class for printer connection handling
    * Add shared WizardFramework for step-based navigation
2026-01-30 Feature/tools landing redesign (#32)
    * Redesign tools landing page as Rep5x Studio
    * Reorganise tools page categories
2026-02-10 Improve tools: EEPROM backup, calibrator, gcode viewer, shared components (#34)
2026-02-16 Add spiral flower shape to vase generator (#35)
2026-03-16 Add gcode file sharing for research (#38)
    * Add gcode-share Pages Function
    * Add share-handler.js client module
    * Add share toggle and wire up file sharing in gcode viewer
2026-03-16 Fix gcode-share email delivery
    * Add info icon to share toggle explaining research purpose
    * Fix gcode-share: add content_type for attachments, expose errors
    * Fix gcode attachment: rename to .txt for EmailIt compatibility
2026-03-16 Add G2/G3 arc support and tube rendering for gcode viewer (#40)
2026-04-20 Add Ender 5 Pro preset and endstop state config (#44)
2026-04-29 Add baud rate selector and fix home() timeout (#45)
    Shared baud selector (localStorage-backed, default 250000) added to
    printer-control, printer-setup, lc-lb-measure, and calibrator. Tools
    were hardcoded to 115200 which silently broke any printer flashed
    with the firmware-builder default of 250000.
    Also fixes home() to use sendCommandAndWait with a 120s timeout instead
    of a fire-and-forget sendCommand + 2s sleep, which falsely errored
    "Position request timeout" on real homing operations.
2026-05-20 Firmware builder: sensorless homing, case light, advanced pin panel (#47)
    * Add Ender 5 Pro preset and endstop state config
    * Add sensorless homing output to firmware config generator
    * Add preview and default-value tests for sensorless config
    * Pass sensorless homing fields through firmware build worker
    * Add sensorless XY homing option to firmware builder wizard
    * Restore driver choice when leaving sensorless mode
    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
2026-05-26 gcode-viewer: auto-load from ?gcodeUrl= query param (#49)
    * Make Download config files button fetch full configs from cloud build
    * gcode-viewer: auto-load from ?gcodeUrl=<url> query param
    OrcaSlicer-Rep5x's 5-axis slice action can now spawn a small local CORS HTTP
    server hosting the just-written .gcode, then open this viewer with
    ?gcodeUrl=http://localhost:PORT/file.gcode and the gcode auto-loads. Falls back
    to manual drag-drop if the URL fetch fails.
2026-07-02 Add thesis flipbook page at /thesis
    Book-spread flipbook (StPageFlip): cover, two-page spreads, fullscreen,
    per-page deep-links, keyboard nav, and a download button. Includes the
    rendered WebP page images and a compressed PDF for download.

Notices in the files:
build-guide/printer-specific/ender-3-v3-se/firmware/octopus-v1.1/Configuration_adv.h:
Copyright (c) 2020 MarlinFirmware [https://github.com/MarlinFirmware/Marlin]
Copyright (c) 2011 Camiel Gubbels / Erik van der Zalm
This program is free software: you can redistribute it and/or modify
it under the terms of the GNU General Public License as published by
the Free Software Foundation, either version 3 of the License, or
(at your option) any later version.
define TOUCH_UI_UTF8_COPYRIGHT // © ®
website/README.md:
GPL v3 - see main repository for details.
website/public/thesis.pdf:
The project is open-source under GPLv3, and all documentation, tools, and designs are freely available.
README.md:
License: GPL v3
